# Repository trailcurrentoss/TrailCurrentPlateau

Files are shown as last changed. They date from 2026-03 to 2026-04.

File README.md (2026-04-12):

# TrailCurrent Plateau

Vehicle leveling module that monitors trailer tilt angles and computes per-corner height adjustments via a CAN bus interface with OTA firmware update capability. Part of the [TrailCurrent](https://trailcurrent.com) open-source vehicle platform.

## Hardware Overview

- **Microcontroller:** ESP32-S3
- **IMU:** Adafruit BNO055 9-DOF Absolute Orientation
- **Function:** Vehicle leveling with CAN bus communication
- **Key Features:**
  - BNO055 IMU for pitch/roll measurement with auto-calibration
  - Per-corner height adjustment calculation from vehicle dimensions
  - Three mounting orientations (floor, left wall, right wall) with axis remapping
  - CAN bus communication at 500 kbps
  - Vehicle configuration (dimensions, mounting) received via CAN and stored in NVS
  - Over-the-air (OTA) firmware updates via WiFi (credentials provisioned via CAN)
  - mDNS-based device discovery for Headwaters integration
  - Custom flash partition layout with dual OTA slots

## Hardware Requirements

### Components

- **Microcontroller:** [Waveshare ESP32-S3-Zero](https://www.waveshare.com/esp32-s3-zero.htm?aff_id=Trailcurrent) — selected for its extensive documentation, small footprint, pre-soldered programming pins, castellations for direct PCB integration, and low power consumption
- **CAN Transceiver:** SN65HVD230
- **Power:** Buck converter (12V step-down)
- **Connectors:** JST XH 2.54 4-pin

### Pin Connections

| GPIO | Function |
|---|---|
| 1 | I2C SDA (BNO055) |
| 2 | I2C SCL (BNO055) |
| 7 | CAN TX |
| 8 | CAN RX |

### KiCAD Library Dependencies

This project uses the consolidated [TrailCurrentKiCADLibraries](https://github.com/trailcurrentoss/TrailCurrentKiCADLibraries).

**Setup:**

```bash
# Clone the library
git clone git@github.com:trailcurrentoss/TrailCurrentKiCADLibraries.git

# Set environment variables (add to ~/.bashrc or ~/.zshrc)
export TRAILCURRENT_SYMBOL_DIR="/path/to/TrailCurrentKiCADLibraries/symbols"
export TRAILCURRENT_FOOTPRINT_DIR="/path/to/TrailCurrentKiCADLibraries/footprints"
export TRAILCURRENT_3DMODEL_DIR="/path/to/TrailCurrentKiCADLibraries/3d_models"
```

See [KICAD_ENVIRONMENT_SETUP.md](https://github.com/trailcurrentoss/TrailCurrentKiCADLibraries/blob/main/KICAD_ENVIRONMENT_SETUP.md) in the library repository for detailed setup instructions.

## Opening the Project

1. **Set up environment variables** (see Library Dependencies above)
2. **Open KiCAD:**
   ```bash
   kicad EDA/TrailCurrentPlateau/TrailCurrentPlateau.kicad_pro
   ```
3. **Verify libraries load** - All symbol and footprint libraries should resolve without errors
4. **View 3D models** - Open PCB and press `Alt+3` to view the 3D visualization

## Firmware

ESP-IDF native firmware in the `main/` directory.

**Prerequisites:**
- [ESP-IDF](https://docs.espressif.com/projects/esp-idf/en/latest/esp32s3/get-started/) v4.1 or later

**Build and flash:**
```bash
# Set ESP-IDF target
idf.py set-target esp32s3

# Build firmware
idf.py build

# Upload to board (serial)
idf.py flash

# Monitor serial output
idf.py monitor

# Build, flash, and monitor in one command
idf.py build flash monitor
```

**OTA update (after initial flash):**
```bash
curl -X POST http://esp32-XXYYZZ.local/ota --data-binary @build/plateau.bin
```

### Firmware Architecture

The firmware uses FreeRTOS tasks for concurrent operation:

| Task | Priority | Stack | Function |
|---|---|---|---|
| twai | 5 | 4096 | CAN bus RX/TX, leveling computation, IMU reads |
| ota | 3 | 8192 | OTA update (spawned on demand, non-blocking) |
| discovery | 3 | 8192 | mDNS discovery (spawned on demand, non-blocking) |

OTA and discovery run as separate tasks to avoid blocking CAN bus communication. Mutual exclusion prevents both from running simultaneously.

### Source Files

| File | Purpose |
|---|---|
| `main.c` | Application entry, TWAI task, leveling logic, CAN protocol |
| `bno055.c/h` | BNO055 IMU driver (bare I2C, no Arduino dependency) |
| `wifi_config.c/h` | WiFi credentials, connect/disconnect, CAN provisioning |
| `ota.c/h` | Task-based OTA with HTTP server and mDNS |
| `discovery.c/h` | Task-based mDNS discovery for Headwaters |

### CAN Bus Protocol

- **Receive ID `0x00`:** OTA update trigger — initiates firmware update when device MAC matches
- **Receive ID `0x01`:** WiFi credential provisioning — multi-frame protocol to store SSID/password in NVS
- **Receive ID `0x02`:** Discovery trigger — joins WiFi, advertises via mDNS, waits for Headwaters confirmation
- **Transmit ID `0x04`:** Firmware version report — sent once on boot: `[mac3, mac4, mac5, major, minor, patch]`
- **Receive ID `0x20`:** Leveling configuration — set mounting surface, vehicle length/width, persist to NVS
- **Transmit ID `0x30`:** Tilt data — pitch/roll angles (×100) and front-back/left-right height diffs in mm
- **Transmit ID `0x31`:** Corner data — per-corner height adjustments in mm (normalized, lowest = 0)
- **Transmit ID `0x32`:** Status data — IMU connection, calibration levels, mounting orientation
- CAN speed: 500 kbps

### WiFi Credentials

WiFi credentials are provisioned over the CAN bus (ID `0x01`) and stored in NVS. No hardcoded credentials or secrets files needed.

## Manufacturing

- **PCB Files:** Ready for fabrication via standard PCB services (JLCPCB, OSH Park, etc.)
- **BOM Generation:** Export BOM from KiCAD schematic (Tools > Generate BOM)
- **JLCPCB Assembly:** See [BOM_ASSEMBLY_WORKFLOW.md](https://github.com/trailcurrentoss/TrailCurrentKiCADLibraries/blob/main/BOM_ASSEMBLY_WORKFLOW.md) for detailed assembly workflow

## Project Structure

```
├── EDA/                          # KiCAD hardware design files
│   └── TrailCurrentPlateau/
│       ├── *.kicad_pro           # KiCAD project
│       ├── *.kicad_sch           # Schematic
│       └── *.kicad_pcb           # PCB layout
├── CAD/                          # FreeCAD PCB enclosure design
├── main/                         # ESP-IDF firmware source
│   ├── main.c                    # Application entry, TWAI task, leveling logic
│   ├── bno055.c/h                # BNO055 IMU I2C driver
│   ├── wifi_config.c/h           # WiFi credentials and CAN provisioning
│   ├── ota.c/h                   # OTA firmware update (task-based)
│   ├── discovery.c/h             # mDNS device discovery (task-based)
│   ├── CMakeLists.txt            # Component build configuration
│   └── idf_component.yml         # ESP-IDF component dependencies
├── CMakeLists.txt                # Root ESP-IDF project file
├── sdkconfig.defaults            # ESP-IDF build defaults
├── partitions.csv                # ESP32 flash partition layout (dual OTA)
├── LICENSE                       # MIT License
└── README.md                     # This file
```

## License

MIT License - See LICENSE file for details.

This is open source hardware. You are free to use, modify, and distribute these designs for personal or commercial purposes.

## Contributing

Improvements and contributions are welcome! Please submit issues or pull requests.

## Support

For questions about:
- **KiCAD setup:** See [KICAD_ENVIRONMENT_SETUP.md](https://github.com/trailcurrentoss/TrailCurrentKiCADLibraries/blob/main/KICAD_ENVIRONMENT_SETUP.md)
- **Assembly workflow:** See [BOM_ASSEMBLY_WORKFLOW.md](https://github.com/trailcurrentoss/TrailCurrentKiCADLibraries/blob/main/BOM_ASSEMBLY_WORKFLOW.md)

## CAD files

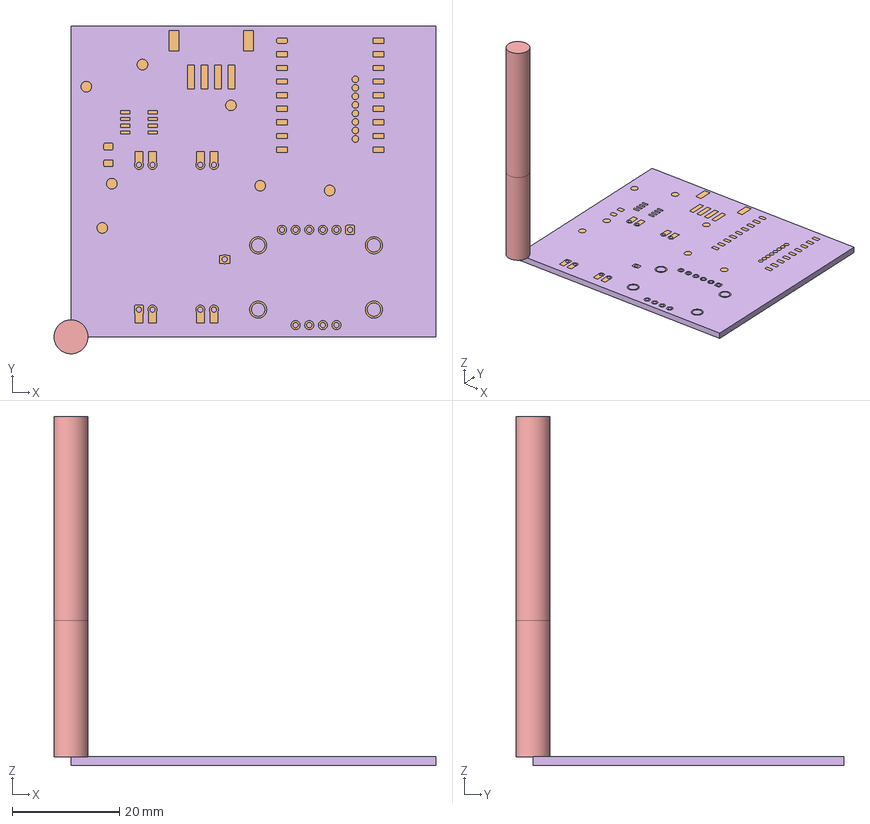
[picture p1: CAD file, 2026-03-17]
CAD/TrailCurrentPlateauForDiyPcbMilling.FCStd
71.3 x 61.1 x 65.1 mm
Model-TrailCurrentPlateau001
Pcb_d97f
topTracks_d97f
botTracks_d97f
SpeTool O Flute 1/4"001
Stock001
0.6mm Drill001
1mm Drill001
2.5mm Drillbit001
topPads_d97f
botPads_d97f
botZones_d97f

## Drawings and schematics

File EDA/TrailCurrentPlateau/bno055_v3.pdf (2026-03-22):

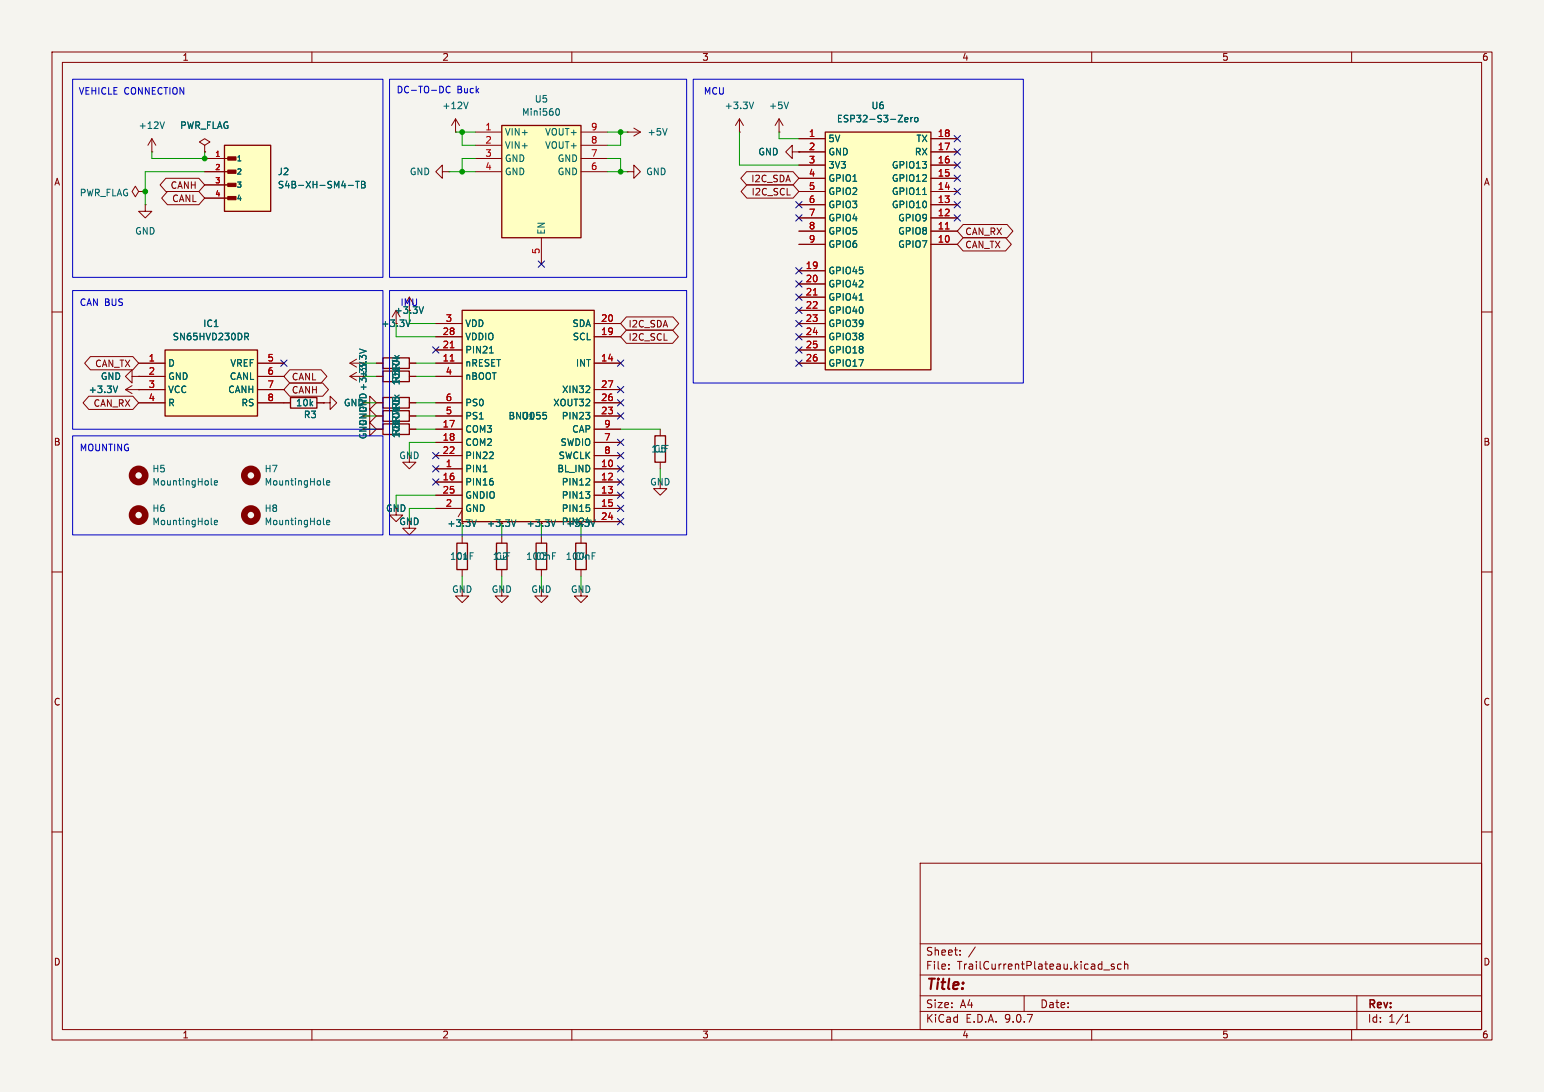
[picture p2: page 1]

5 VOUT+ 9 VOUT+ 8 GND 7 GND 6 U5 Mini560 GND GND GND

Id: 1/1 Title: File: TrailCurrentPlateau.kicad_sch Sheet: /

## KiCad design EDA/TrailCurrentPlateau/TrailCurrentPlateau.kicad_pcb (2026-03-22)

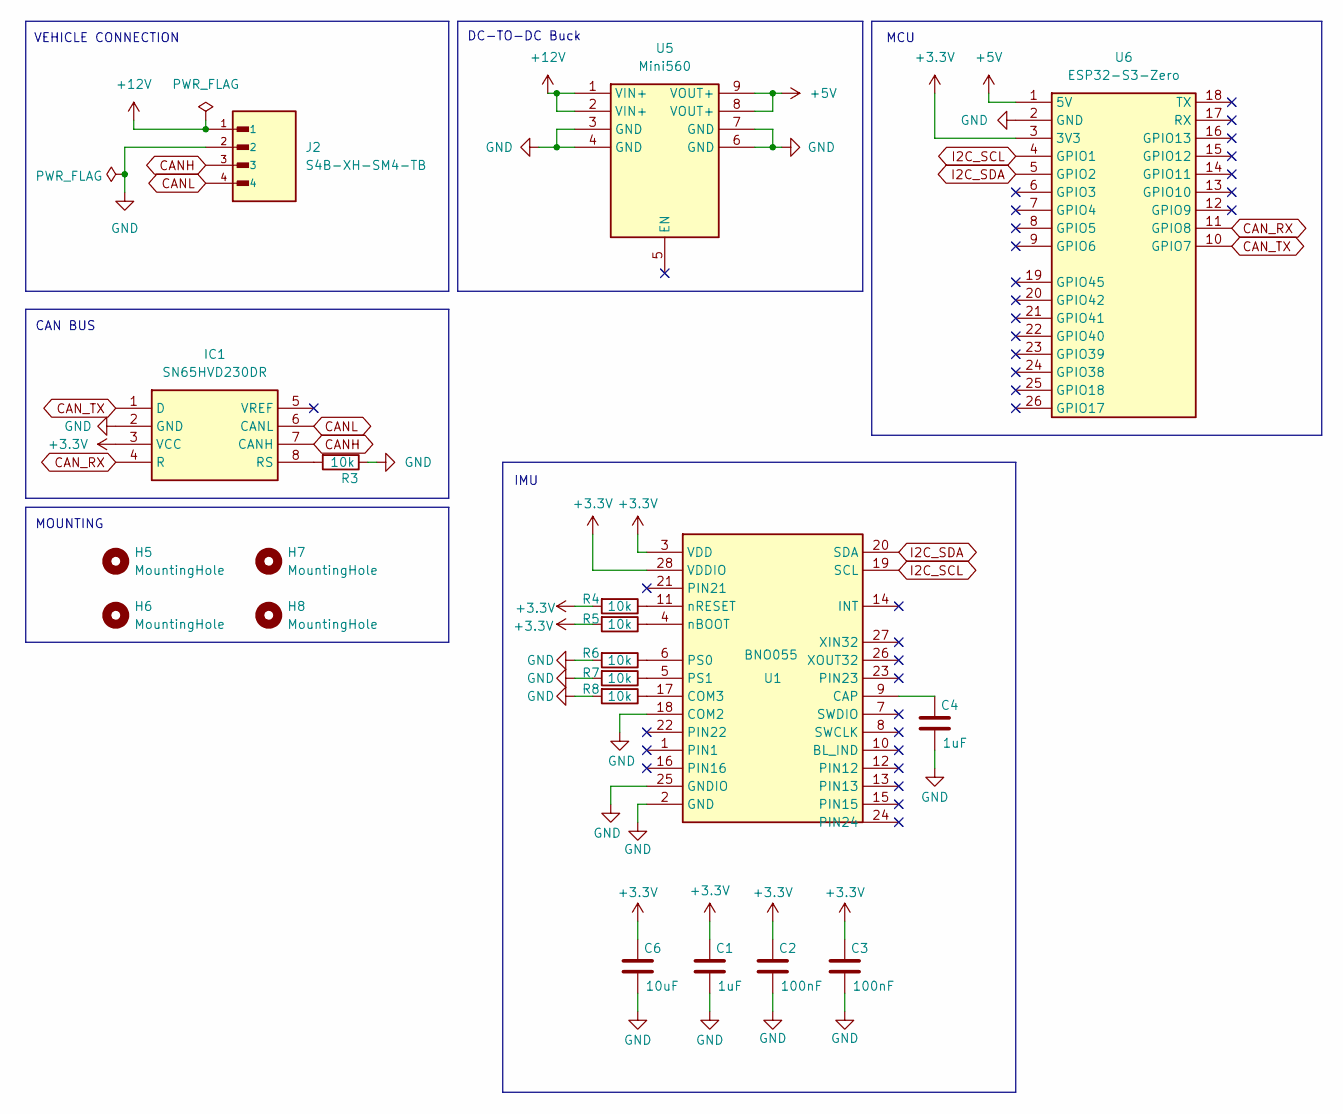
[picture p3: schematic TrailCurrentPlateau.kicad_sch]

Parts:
C1, C4: 1uF; C_1206_3216Metric
C2, C3: 100nF; C_1206_3216Metric
C6: 10uF; C_1206_3216Metric
H5, H6, H7, H8: MountingHole; MountingHole_2.5mm
IC1: SN65HVD230DR; Mouser Part Number 595-SN65HVD230DR
J2: S4B-XH-SM4-TB; JST_S4B-XH-SM4-TB; LCSC Part C161861
R3, R4, R5, R6, R7, R8: 10k; R_1206_3216Metric_Pad1.30x1.75mm_HandSolder
U1: BNO055; BNO055_LGA-28_3.8x5.2mm
U5: Mini560; Manufacturer_Part_Number Mini560
U6: ESP32-S3-Zero; ESP32-S3-Zero_TH; Manufacturer_Part_Number ESP32-S3-Zero

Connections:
+3.3V: C1.1, C2.1, C3.1, C6.1, IC1.3 (VCC), R4.2, R5.2, U1.3 (VDD), U1.28 (VDDIO), U6.3 (3V3)
+5V: U5.8 (VOUT+), U5.9 (VOUT+), U6.1 (5V)
+12V: J2.1, U5.1 (VIN+), U5.2 (VIN+)
CANH: IC1.7 (CANH), J2.3
CANL: IC1.6 (CANL), J2.4
CAN_RX: IC1.4 (R), U6.11 (GPIO8)
CAN_TX: IC1.1 (D), U6.10 (GPIO7)
GND: C1.2, C2.2, C3.2, C4.2, C6.2, IC1.2 (GND), J2.2, R3.1, R6.2, R7.2, R8.2, U1.2 (GND), U1.18 (COM2), U1.25 (GNDIO), U5.3 (GND), U5.4 (GND), U5.6 (GND), U5.7 (GND), U6.2 (GND)
I2C_SCL: U1.19 (SCL), U6.4 (GPIO1)
I2C_SDA: U1.20 (SDA), U6.5 (GPIO2)
unnamed: IC1.8 (RS), R3.2
unnamed: C4.1, U1.9 (CAP)
unnamed: R8.1, U1.17 (COM3)
unnamed: R6.1, U1.6 (PS0)
unnamed: R7.1, U1.5 (PS1)
unnamed: R5.1, U1.4 (nBOOT)
unnamed: R4.1, U1.11 (nRESET)

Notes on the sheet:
IMU
DC-TO-DC Buck
MCU
VEHICLE CONNECTION
MOUNTING
CAN BUS

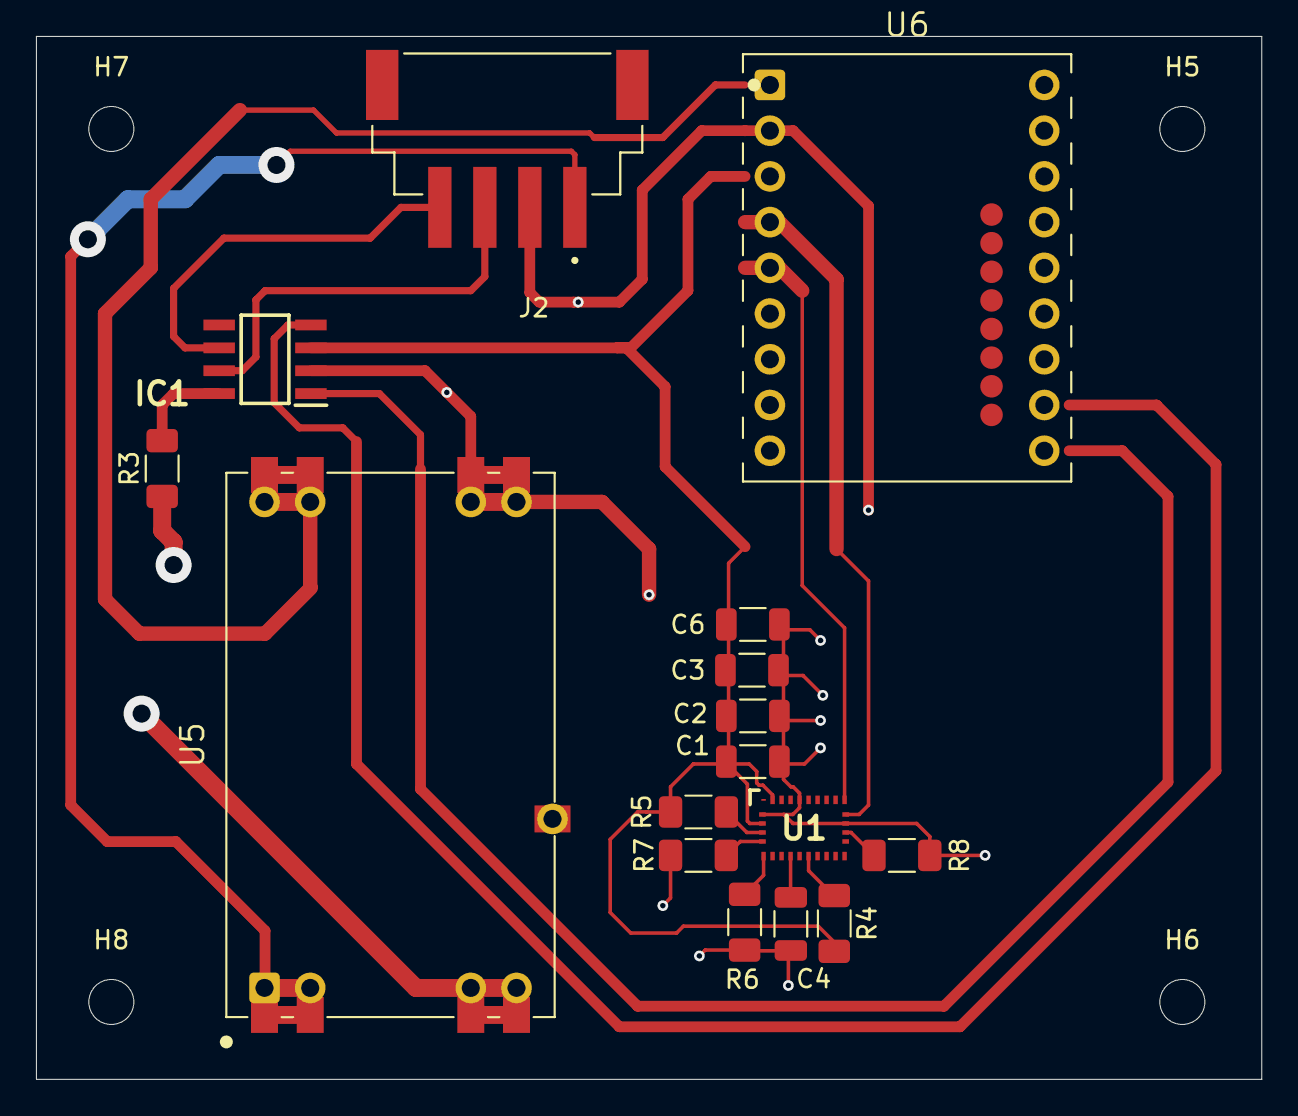
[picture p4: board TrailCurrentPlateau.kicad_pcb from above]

Board: 2 copper layers, 68.1 x 57.9 mm, 20 parts (0 on the bottom side), 17 nets.

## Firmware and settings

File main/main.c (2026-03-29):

#include <stdio.h>
#include <string.h>
#include <math.h>
#include "freertos/FreeRTOS.h"
#include "freertos/task.h"
#include "driver/twai.h"
#include "esp_log.h"
#include "esp_timer.h"
#include "esp_app_desc.h"
#include "esp_mac.h"
#include "nvs.h"

#include "bno055.h"
#include "wifi_config.h"
#include "ota.h"
#include "discovery.h"

static const char *TAG = "plateau";

// =============================================================================
// Pin Definitions — ESP32-S3-Zero
// =============================================================================

#define I2C_SDA_PIN  1
#define I2C_SCL_PIN  2
#define CAN_TX_PIN   7
#define CAN_RX_PIN   8

// =============================================================================
// CAN Bus Configuration
// =============================================================================

#define CAN_ID_OTA_TRIGGER       0x00
#define CAN_ID_WIFI_CONFIG       0x01
#define CAN_ID_DISCOVERY_TRIGGER 0x02
#define CAN_ID_LEVELING_CFG      0x20
#define CAN_ID_TILT_DATA         0x30
#define CAN_ID_CORNER_DATA       0x31
#define CAN_ID_STATUS_DATA       0x32

#define STATUS_TX_INTERVAL_MS    33    // ~30 Hz
#define TX_PROBE_INTERVAL_MS     2000  // slow probe when no peers

// =============================================================================
// Timing
// =============================================================================

#define LEVELING_INTERVAL_US     (500 * 1000LL)   // 500 ms
#define STATUS_INTERVAL_US       (2000 * 1000LL)  // 2 s
#define IMU_RETRY_INTERVAL_US    (5000 * 1000LL)  // 5 s

// =============================================================================
// Leveling State
// =============================================================================

typedef struct {
    bno055_mount_t mounting;
    uint16_t vehicle_length_cm;
    uint16_t vehicle_width_cm;
} leveling_config_t;

typedef struct {
    float pitch_deg;
    float roll_deg;
    int16_t front_back_diff_mm;
    int16_t left_right_diff_mm;
    bno055_cal_status_t cal;
    bool imu_connected;
} leveling_data_t;

static leveling_config_t s_config;
static leveling_data_t s_data;
static bool s_has_stored_offsets = false;

// =============================================================================
// NVS — Leveling Config
// =============================================================================

static void save_leveling_config(void)
{
    nvs_handle_t handle;
    if (nvs_open("leveling", NVS_READWRITE, &handle) != ESP_OK) return;
    nvs_set_u8(handle, "mounting", (uint8_t)s_config.mounting);
    nvs_set_u16(handle, "length_cm", s_config.vehicle_length_cm);
    nvs_set_u16(handle, "width_cm", s_config.vehicle_width_cm);
    nvs_commit(handle);
    nvs_close(handle);
    ESP_LOGI(TAG, "Leveling config saved to NVS");
}

static void load_leveling_config(void)
{
    nvs_handle_t handle;
    if (nvs_open("leveling", NVS_READONLY, &handle) != ESP_OK) {
        // Defaults
        s_config.mounting = MOUNT_FLOOR;
        s_config.vehicle_length_cm = 500;
        s_config.vehicle_width_cm = 200;
        return;
    }

    uint8_t mount_val = 0;
    nvs_get_u8(handle, "mounting", &mount_val);
    s_config.mounting = (bno055_mount_t)mount_val;

    uint16_t len = 500, wid = 200;
    nvs_get_u16(handle, "length_cm", &len);
    nvs_get_u16(handle, "width_cm", &wid);
    s_config.vehicle_length_cm = len;
    s_config.vehicle_width_cm = wid;
    nvs_close(handle);

    ESP_LOGI(TAG, "Loaded config: mount=%d, length=%dcm, width=%dcm",
             s_config.mounting, s_config.vehicle_length_cm, s_config.vehicle_width_cm);
}

// =============================================================================
// NVS — BNO055 Calibration Offsets
// =============================================================================

static bool load_calibration_offsets(void)
{
    nvs_handle_t handle;
    if (nvs_open("bno_cal", NVS_READONLY, &handle) != ESP_OK) return false;

    uint8_t valid = 0;
    nvs_get_u8(handle, "valid", &valid);
    if (!valid) {
        nvs_close(handle);
        return false;
    }

    bno055_offsets_t offsets;
    size_t len = sizeof(offsets);
    if (nvs_get_blob(handle, "offsets", &offsets, &len) != ESP_OK) {
        nvs_close(handle);
        return false;
    }
    nvs_close(handle);

    // Must be in CONFIG mode to set offsets
    bno055_set_mode(BNO055_MODE_CONFIG);
    bno055_set_offsets(&offsets);

    ESP_LOGI(TAG, "Calibration offsets loaded from NVS");
    return true;
}

static bool save_and_verify_calibration(void)
{
    bno055_offsets_t written;
    bno055_set_mode(BNO055_MODE_CONFIG);
    if (bno055_get_offsets(&written) != ESP_OK) return false;

    nvs_handle_t handle;
    if (nvs_open("bno_cal", NVS_READWRITE, &handle) != ESP_OK) return false;
    nvs_set_blob(handle, "offsets", &written, sizeof(written));
    nvs_set_u8(handle, "valid", 1);

    // Read back and verify
    bno055_offsets_t readback;
    size_t len = sizeof(readback);
    nvs_get_blob(handle, "offsets", &readback, &len);
    uint8_t valid = 0;
    nvs_get_u8(handle, "valid", &valid);
    nvs_commit(handle);
    nvs_close(handle);

    if (!valid || memcmp(&written, &readback, sizeof(written)) != 0) {
        ESP_LOGE(TAG, "Calibration save FAILED verification");
        return false;
    }

    ESP_LOGI(TAG, "Calibration offsets saved and verified");
    return true;
}

// =============================================================================
// Leveling Computation
// =============================================================================

static void compute_leveling(void)
{
    bno055_vec3_t accel;
    if (bno055_read_accel(&accel) != ESP_OK) return;

    s_data.pitch_deg = atan2f(accel.x, sqrtf(accel.y * accel.y + accel.z * accel.z)) * (180.0f / M_PI);
    s_data.roll_deg  = atan2f(accel.y, accel.z) * (180.0f / M_PI);

    float pitch_rad = s_data.pitch_deg * (M_PI / 180.0f);
    float roll_rad  = s_data.roll_deg * (M_PI / 180.0f);

    s_data.front_back_diff_mm = (int16_t)(s_config.vehicle_length_cm * 10.0f * tanf(pitch_rad));
    s_data.left_right_diff_mm = (int16_t)(s_config.vehicle_width_cm * 10.0f * tanf(roll_rad));

    bno055_get_cal_status(&s_data.cal);
}

// =============================================================================
// CAN Transmit Helpers
// =============================================================================

static void send_leveling_data(twai_message_t *tx_msg)
{
    // Tilt + height diffs
    tx_msg->identifier = CAN_ID_TILT_DATA;
    tx_msg->data_length_code = 8;

    int16_t pitch100 = (int16_t)(s_data.pitch_deg * 100.0f);
    int16_t roll100  = (int16_t)(s_data.roll_deg * 100.0f);

    tx_msg->data[0] = (pitch100 >> 8) & 0xFF;
    tx_msg->data[1] = pitch100 & 0xFF;
    tx_msg->data[2] = (roll100 >> 8) & 0xFF;
    tx_msg->data[3] = roll100 & 0xFF;
    tx_msg->data[4] = (s_data.front_back_diff_mm >> 8) & 0xFF;
    tx_msg->data[5] = s_data.front_back_diff_mm & 0xFF;
    tx_msg->data[6] = (s_data.left_right_diff_mm >> 8) & 0xFF;
    tx_msg->data[7] = s_data.left_right_diff_mm & 0xFF;
    twai_transmit(tx_msg, 0);

    // Corner adjustments normalized to lowest = 0
    int16_t fl = s_data.front_back_diff_mm / 2 + s_data.left_right_diff_mm / 2;
    int16_t fr = s_data.front_back_diff_mm / 2 - s_data.left_right_diff_mm / 2;
    int16_t rl = -s_data.front_back_diff_mm / 2 + s_data.left_right_diff_mm / 2;
    int16_t rr = -s_data.front_back_diff_mm / 2 - s_data.left_right_diff_mm / 2;

    int16_t min_val = fl;
    if (fr < min_val) min_val = fr;
    if (rl < min_val) min_val = rl;
    if (rr < min_val) min_val = rr;
    fl -= min_val;
    fr -= min_val;
    rl -= min_val;
    rr -= min_val;

    tx_msg->identifier = CAN_ID_CORNER_DATA;
    tx_msg->data[0] = (fl >> 8) & 0xFF;
    tx_msg->data[1] = fl & 0xFF;
    tx_msg->data[2] = (fr >> 8) & 0xFF;
    tx_msg->data[3] = fr & 0xFF;
    tx_msg->data[4] = (rl >> 8) & 0xFF;
    tx_msg->data[5] = rl & 0xFF;
    tx_msg->data[6] = (rr >> 8) & 0xFF;
    tx_msg->data[7] = rr & 0xFF;
    twai_transmit(tx_msg, 0);
}

static void send_status_data(twai_message_t *tx_msg)
{
    tx_msg->identifier = CAN_ID_STATUS_DATA;
    tx_msg->data_length_code = 4;

    uint8_t flags = 0;
    if (s_data.imu_connected) flags |= 0x01;
    if (s_has_stored_offsets) flags |= 0x02;

    uint8_t cal_packed = (s_data.cal.sys << 6) | (s_data.cal.gyro << 4) |
                         (s_data.cal.accel << 2) | s_data.cal.mag;

    tx_msg->data[0] = flags;
    tx_msg->data[1] = cal_packed;
    tx_msg->data[2] = (uint8_t)s_config.mounting;
    tx_msg->data[3] = 0x00;
    twai_transmit(tx_msg, 0);
}

// =============================================================================
// CAN RX Handlers
// =============================================================================

static void handle_leveling_config(const uint8_t *data, uint8_t len)
{
    if (len < 1) return;

    switch (data[0]) {
    case 0x01: {
        if (len < 7) return;
        uint8_t mount_val = data[1];
        if (mount_val <= MOUNT_RIGHT_WALL) {
            s_config.mounting = (bno055_mount_t)mount_val;
        }
        s_config.vehicle_length_cm = (data[2] << 8) | data[3];
        s_config.vehicle_width_cm  = (data[4] << 8) | data[5];

        bno055_apply_axis_remap(s_config.mounting,
            s_has_stored_offsets ? BNO055_MODE_ACCONLY : BNO055_MODE_NDOF);

        if (data[6] == 0x01) {
            save_leveling_config();
        }

        ESP_LOGI(TAG, "Config updated: mount=%d, length=%dcm, width=%dcm",
                 s_config.mounting, s_config.vehicle_length_cm, s_config.vehicle_width_cm);
        break;
    }
    case 0x02: {
        // Status request — will be sent on next status interval
        break;
    }
    case 0x03: {
        ESP_LOGI(TAG, "Save calibration requested");
        if (save_and_verify_calibration()) {
            s_has_stored_offsets = true;
            bno055_apply_axis_remap(s_config.mounting, BNO055_MODE_ACCONLY);
            ESP_LOGI(TAG, "Calibration saved — switched to ACCONLY");
        }
        break;
    }
    }
}

// =============================================================================
// TWAI (CAN) task — runs independently
// =============================================================================

static void twai_task(void *arg)
{
    twai_general_config_t g_config = TWAI_GENERAL_CONFIG_DEFAULT(
        (gpio_num_t)CAN_TX_PIN, (gpio_num_t)CAN_RX_PIN, TWAI_MODE_NORMAL);
    twai_timing_config_t t_config = TWAI_TIMING_CONFIG_500KBITS();
    twai_filter_config_t f_config = TWAI_FILTER_CONFIG_ACCEPT_ALL();

    if (twai_driver_install(&g_config, &t_config, &f_config) != ESP_OK) {
        ESP_LOGE(TAG, "Failed to install TWAI driver");
        vTaskDelete(NULL);
        return;
    }
    if (twai_start() != ESP_OK) {
        ESP_LOGE(TAG, "Failed to start TWAI driver");
        vTaskDelete(NULL);
        return;
    }

    // Broadcast firmware version on CAN 0x04 at startup
    {
        uint8_t mac[6];
        esp_read_mac(mac, ESP_MAC_WIFI_STA);
        const esp_app_desc_t *app = esp_app_get_description();
        unsigned maj = 0, min = 0, pat = 0;
        sscanf(app->version, "%u.%u.%u", &maj, &min, &pat);
        twai_message_t ver_msg = {
            .identifier = 0x04,
            .data_length_code = 6,
            .data = { mac[3], mac[4], mac[5], maj, min, pat }
        };
        twai_transmit(&ver_msg, pdMS_TO_TICKS(50));
        ESP_LOGI(TAG, "Version broadcast: %s (CAN 0x04)", app->version);
    }

    uint32_t alerts = TWAI_ALERT_RX_DATA | TWAI_ALERT_ERR_PASS |
                      TWAI_ALERT_BUS_ERROR | TWAI_ALERT_RX_QUEUE_FULL |
                      TWAI_ALERT_BUS_OFF | TWAI_ALERT_BUS_RECOVERED |
                      TWAI_ALERT_ERR_ACTIVE | TWAI_ALERT_TX_FAILED |
                      TWAI_ALERT_TX_SUCCESS;
    twai_reconfigure_alerts(alerts, NULL);
    ESP_LOGI(TAG, "TWAI driver started (NORMAL mode, 500 kbps)");

    typedef enum { TX_ACTIVE, TX_PROBING } tx_state_t;
    bool bus_off = false;
    tx_state_t tx_state = TX_ACTIVE;
    int tx_fail_count = 0;
    const int TX_FAIL_THRESHOLD = 3;
    int64_t last_tx_us = 0;
    const int64_t tx_period_us = STATUS_TX_INTERVAL_MS * 1000LL;
    const int64_t tx_probe_period_us = TX_PROBE_INTERVAL_MS * 1000LL;

    // Leveling timing
    int64_t last_leveling_us = 0;
    int64_t last_status_us = 0;
    int64_t last_imu_retry_us = 0;

    twai_message_t tx_msg = {0};

    while (1) {
        uint32_t triggered;
        twai_read_alerts(&triggered, pdMS_TO_TICKS(10));

        // --- Bus error handling ---
        if (triggered & TWAI_ALERT_BUS_OFF) {
            ESP_LOGE(TAG, "TWAI bus-off, initiating recovery");
            bus_off = true;
            twai_initiate_recovery();
            continue;
        }
        if (triggered & TWAI_ALERT_BUS_RECOVERED) {
            ESP_LOGI(TAG, "TWAI bus recovered, restarting");
            twai_start();
            bus_off = false;
            tx_fail_count = 0;
            tx_state = TX_PROBING;
        }
        if (triggered & TWAI_ALERT_ERR_PASS) {
            ESP_LOGW(TAG, "TWAI error passive (no peers ACKing?)");
        }
        if (triggered & TWAI_ALERT_TX_FAILED) {
            if (tx_state == TX_ACTIVE) {
                tx_fail_count++;
                if (tx_fail_count >= TX_FAIL_THRESHOLD) {
                    tx_state = TX_PROBING;
                    ESP_LOGW(TAG, "TWAI no peers detected, entering slow probe");
                }
            }
        }
        if (triggered & TWAI_ALERT_TX_SUCCESS) {
            if (tx_state == TX_PROBING) {
                tx_state = TX_ACTIVE;
                tx_fail_count = 0;
                ESP_LOGI(TAG, "TWAI probe ACK'd, peer detected, resuming normal TX");
            }
            tx_fail_count = 0;
        }

        // --- Drain received messages ---
        if (triggered & TWAI_ALERT_RX_DATA) {
            if (tx_state == TX_PROBING) {
                tx_state = TX_ACTIVE;
                tx_fail_count = 0;
                ESP_LOGI(TAG, "TWAI peer detected via RX, resuming normal TX");
            }
            twai_message_t msg;
            while (twai_receive(&msg, 0) == ESP_OK) {
                if (msg.rtr) continue;

                if (msg.identifier == CAN_ID_OTA_TRIGGER) {
                    ota_handle_trigger(msg.data, msg.data_length_code);
                } else if (msg.identifier == CAN_ID_WIFI_CONFIG) {
                    wifi_config_handle_can(msg.data, msg.data_length_code);
                } else if (msg.identifier == CAN_ID_DISCOVERY_TRIGGER) {
                    discovery_handle_trigger();
                } else if (msg.identifier == CAN_ID_LEVELING_CFG) {
                    handle_leveling_config(msg.data, msg.data_length_code);
                }
            }
        }

        // --- WiFi config timeout check ---
        wifi_config_check_timeout();

        // --- IMU retry if disconnected ---
        int64_t now_us = esp_timer_get_time();

        if (!s_data.imu_connected) {
            if (now_us - last_imu_retry_us >= IMU_RETRY_INTERVAL_US) {
                last_imu_retry_us = now_us;
                if (bno055_is_connected()) {
                    s_data.imu_connected = true;
                    ESP_LOGI(TAG, "BNO055 connected on retry");
                    s_has_stored_offsets = load_calibration_offsets();
                    bno055_apply_axis_remap(s_config.mounting,
                        s_has_stored_offsets ? BNO055_MODE_ACCONLY : BNO055_MODE_NDOF);
                }
            }
            // Skip leveling when IMU is disconnected
            continue;
        }

        // --- Read IMU and compute leveling at 500 ms intervals ---
        if (now_us - last_leveling_us >= LEVELING_INTERVAL_US) {
            last_leveling_us = now_us;
            compute_leveling();
        }

        // --- Periodic CAN transmit ---
        int64_t effective_period = (tx_state == TX_PROBING) ? tx_probe_period_us : tx_period_us;
        if (!bus_off && (now_us - last_tx_us >= effective_period)) {
            last_tx_us = now_us;

            // Send leveling data with tilt+corner frames
            if (s_data.imu_connected) {
                send_leveling_data(&tx_msg);
            }
        }

        // --- Status at 2 s intervals ---
        if (!bus_off && (now_us - last_status_us >= STATUS_INTERVAL_US)) {
            last_status_us = now_us;
            send_status_data(&tx_msg);
        }
    }
}

// =============================================================================
// Main application
// =============================================================================

void app_main(void)
{
    // Initialize NVS and WiFi config
    wifi_config_init();
    char ssid[33], password[64];
    if (wifi_config_load(ssid, sizeof(ssid), password, sizeof(password))) {
        ESP_LOGI(TAG, "WiFi credentials loaded");
    } else {
        ESP_LOGW(TAG, "No WiFi credentials — OTA disabled until provisioned via CAN");
    }

    ota_init();
    discovery_init();

    ESP_LOGI(TAG, "=== TrailCurrent Plateau ===");
    ESP_LOGI(TAG, "Vehicle Leveling Module");
    ESP_LOGI(TAG, "Hostname: %s", wifi_config_get_hostname());

    // Initialize BNO055 IMU
    if (bno055_init(I2C_SDA_PIN, I2C_SCL_PIN) == ESP_OK) {
        s_data.imu_connected = true;
        ESP_LOGI(TAG, "BNO055 detected");

        s_has_stored_offsets = load_calibration_offsets();
    } else {
        s_data.imu_connected = false;
        ESP_LOGW(TAG, "BNO055 not found — will retry");
    }

    // Load leveling config from NVS
    load_leveling_config();

    // Apply axis remap and set operating mode
    if (s_data.imu_connected) {
        if (s_has_stored_offsets) {
            bno055_apply_axis_remap(s_config.mounting, BNO055_MODE_ACCONLY);
            ESP_LOGI(TAG, "Offsets loaded — ACCONLY mode, ready to level");
        } else {
            bno055_apply_axis_remap(s_config.mounting, BNO055_MODE_NDOF);
            ESP_LOGI(TAG, "No stored offsets — NDOF mode for initial calibration");
        }
    }

    // CAN runs in its own task so bus errors never block app_main
    xTaskCreatePinnedToCore(twai_task, "twai", 4096, NULL, 5, NULL, 1);

    ESP_LOGI(TAG, "Setup complete");

    // Main task has nothing else to do — park it
    while (1) {
        vTaskDelay(pdMS_TO_TICKS(1000));
    }
}

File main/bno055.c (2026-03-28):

#include "bno055.h"

#include <string.h>
#include "freertos/FreeRTOS.h"
#include "freertos/task.h"
#include "esp_log.h"

static const char *TAG = "bno055";

// ---------------------------------------------------------------------------
// BNO055 register addresses
// ---------------------------------------------------------------------------

#define REG_CHIP_ID         0x00
#define REG_ACC_DATA_X_LSB  0x08
#define REG_CALIB_STAT      0x35
#define REG_OPR_MODE        0x3D
#define REG_AXIS_MAP_CONFIG 0x41
#define REG_AXIS_MAP_SIGN   0x42
#define REG_ACC_OFFSET_X_LSB 0x55

#define BNO055_CHIP_ID_VALUE 0xA0
#define ACC_SCALE            100.0f  // BNO055 accelerometer LSB = 1/100 m/s^2

// Mode switch delay (datasheet: 7ms from any to CONFIG, 19ms from CONFIG to any)
#define MODE_SWITCH_DELAY_MS 25

// ---------------------------------------------------------------------------
// I2C bus handle
// ---------------------------------------------------------------------------

static i2c_master_bus_handle_t s_bus = NULL;
static i2c_master_dev_handle_t s_dev = NULL;
static bool s_connected = false;

// ---------------------------------------------------------------------------
// Low-level I2C helpers
// ---------------------------------------------------------------------------

static esp_err_t bno055_write_reg(uint8_t reg, uint8_t value)
{
    uint8_t buf[2] = { reg, value };
    return i2c_master_transmit(s_dev, buf, 2, 100);
}

static esp_err_t bno055_read_reg(uint8_t reg, uint8_t *out, size_t len)
{
    return i2c_master_transmit_receive(s_dev, &reg, 1, out, len, 100);
}

// ---------------------------------------------------------------------------
// Public API
// ---------------------------------------------------------------------------

esp_err_t bno055_init(int sda_pin, int scl_pin)
{
    // Configure I2C master bus
    i2c_master_bus_config_t bus_cfg = {
        .i2c_port = I2C_NUM_0,
        .sda_io_num = sda_pin,
        .scl_io_num = scl_pin,
        .clk_source = I2C_CLK_SRC_DEFAULT,
        .glitch_ignore_cnt = 7,
        .flags.enable_internal_pullup = true,
    };

    esp_err_t ret = i2c_new_master_bus(&bus_cfg, &s_bus);
    if (ret != ESP_OK) {
        ESP_LOGE(TAG, "I2C bus init failed: %s", esp_err_to_name(ret));
        return ret;
    }

    // Add BNO055 device
    i2c_device_config_t dev_cfg = {
        .dev_addr_length = I2C_ADDR_BIT_LEN_7,
        .device_address = BNO055_ADDR,
        .scl_speed_hz = 400000,
    };

    ret = i2c_master_bus_add_device(s_bus, &dev_cfg, &s_dev);
    if (ret != ESP_OK) {
        ESP_LOGE(TAG, "I2C device add failed: %s", esp_err_to_name(ret));
        return ret;
    }

    // Allow I2C peripheral to settle
    vTaskDelay(pdMS_TO_TICKS(100));

    // Verify chip ID
    uint8_t chip_id = 0;
    ret = bno055_read_reg(REG_CHIP_ID, &chip_id, 1);
    if (ret != ESP_OK || chip_id != BNO055_CHIP_ID_VALUE) {
        ESP_LOGE(TAG, "BNO055 not detected (chip_id=0x%02X, expected 0x%02X)",
                 chip_id, BNO055_CHIP_ID_VALUE);
        s_connected = false;
        return ESP_ERR_NOT_FOUND;
    }

    s_connected = true;
    ESP_LOGI(TAG, "BNO055 detected (chip_id=0x%02X)", chip_id);
    return ESP_OK;
}

bool bno055_is_connected(void)
{
    if (!s_connected || s_dev == NULL) return false;

    uint8_t chip_id = 0;
    esp_err_t ret = bno055_read_reg(REG_CHIP_ID, &chip_id, 1);
    if (ret != ESP_OK || chip_id != BNO055_CHIP_ID_VALUE) {
        s_connected = false;
        return false;
    }
    return true;
}

esp_err_t bno055_set_mode(uint8_t mode)
{
    esp_err_t ret = bno055_write_reg(REG_OPR_MODE, mode);
    if (ret != ESP_OK) return ret;
    vTaskDelay(pdMS_TO_TICKS(MODE_SWITCH_DELAY_MS));
    return ESP_OK;
}

esp_err_t bno055_apply_axis_remap(bno055_mount_t mount, uint8_t target_mode)
{
    esp_err_t ret = bno055_set_mode(BNO055_MODE_CONFIG);
    if (ret != ESP_OK) return ret;

    switch (mount) {
    case MOUNT_FLOOR:
        // P1 default: REMAP_CONFIG=0x24, REMAP_SIGN=0x00
        bno055_write_reg(REG_AXIS_MAP_CONFIG, 0x24);
        bno055_write_reg(REG_AXIS_MAP_SIGN, 0x00);
        break;

    case MOUNT_LEFT_WALL:
        // X=X, Y=Z, Z=Y with Z sign flipped
        bno055_write_reg(REG_AXIS_MAP_CONFIG, 0x18);
        bno055_write_reg(REG_AXIS_MAP_SIGN, 0x01);
        break;

    case MOUNT_RIGHT_WALL:
        // X=X, Y=Z, Z=Y with Y sign flipped
        bno055_write_reg(REG_AXIS_MAP_CONFIG, 0x18);
        bno055_write_reg(REG_AXIS_MAP_SIGN, 0x02);
        break;
    }

    return bno055_set_mode(target_mode);
}

esp_err_t bno055_read_accel(bno055_vec3_t *out)
{
    uint8_t buf[6];
    esp_err_t ret = bno055_read_reg(REG_ACC_DATA_X_LSB, buf, 6);
    if (ret != ESP_OK) return ret;

    int16_t raw_x = (int16_t)((buf[1] << 8) | buf[0]);
    int16_t raw_y = (int16_t)((buf[3] << 8) | buf[2]);
    int16_t raw_z = (int16_t)((buf[5] << 8) | buf[4]);

    out->x = raw_x / ACC_SCALE;
    out->y = raw_y / ACC_SCALE;
    out->z = raw_z / ACC_SCALE;

    return ESP_OK;
}

esp_err_t bno055_get_cal_status(bno055_cal_status_t *out)
{
    uint8_t cal = 0;
    esp_err_t ret = bno055_read_reg(REG_CALIB_STAT, &cal, 1);
    if (ret != ESP_OK) return ret;

    out->sys   = (cal >> 6) & 0x03;
    out->gyro  = (cal >> 4) & 0x03;
    out->accel = (cal >> 2) & 0x03;
    out->mag   = cal & 0x03;

    return ESP_OK;
}

esp_err_t bno055_get_offsets(bno055_offsets_t *out)
{
    // Offsets are 22 bytes starting at REG_ACC_OFFSET_X_LSB
    uint8_t buf[22];
    esp_err_t ret = bno055_read_reg(REG_ACC_OFFSET_X_LSB, buf, 22);
    if (ret != ESP_OK) return ret;

    out->accel_offset_x = (int16_t)((buf[1]  << 8) | buf[0]);
    out->accel_offset_y = (int16_t)((buf[3]  << 8) | buf[2]);
    out->accel_offset_z = (int16_t)((buf[5]  << 8) | buf[4]);
    out->mag_offset_x   = (int16_t)((buf[7]  << 8) | buf[6]);
    out->mag_offset_y   = (int16_t)((buf[9]  << 8) | buf[8]);
    out->mag_offset_z   = (int16_t)((buf[11] << 8) | buf[10]);
    out->gyro_offset_x  = (int16_t)((buf[13] << 8) | buf[12]);
    out->gyro_offset_y  = (int16_t)((buf[15] << 8) | buf[14]);
    out->gyro_offset_z  = (int16_t)((buf[17] << 8) | buf[16]);
    out->accel_radius   = (int16_t)((buf[19] << 8) | buf[18]);
    out->mag_radius     = (int16_t)((buf[21] << 8) | buf[20]);

    return ESP_OK;
}
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

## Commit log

2026-03-15 Moved to ESP32S3 Zero board, adafruit bno055 and standard approach for CAN Bus and OTA
    [TrailCurrentPlateau.kicad_pcb, TrailCurrentPlateau.kicad_sch]
2026-03-15 DIY EDA ready, CAM milling oeprations added
    [TrailCurrentPlateau.kicad_pcb, TrailCurrentPlateauForDiyPcbMilling.FCStd]
2026-03-16 EDA Changes to fix Adafruit BNO055 older style footprint
    [TrailCurrentPlateau.kicad_pcb, TrailCurrentPlateauForDiyPcbMilling.FCStd]
2026-03-17 Updated toolpaths with revised BNO055 footprint
    [TrailCurrentPlateauForDiyPcbMilling.FCStd]
2026-03-22 Updates to improve the calibration process and communicate that to headwaters.
    [TrailCurrentPlateau.kicad_pcb, TrailCurrentPlateau.kicad_sch]
2026-03-28 Moved to ESP-IDF
    [partitions.csv]
2026-03-28 Fixing issue with CAN Bus stops responding when discovery happens
    [main.c]
2026-04-12 Adding discovery for this device
2026-10-21 Plateau moved to the ESP32-S3-RS485-CAN board and the DFRobot IMU
